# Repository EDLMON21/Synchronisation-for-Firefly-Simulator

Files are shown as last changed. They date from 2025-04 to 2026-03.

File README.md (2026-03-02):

## 🔥 Project Overview – *Synchronization for Firefly Simulator*  
### 🧠 Team Number: MON-21

👥 **Team Members:**  
- Mohammad Sami  
- Shivam Panwar  
- Gogineni Venkat Sumanth  
- Juluva Yashwanth  
- Lokesh  

---

### 📌 Problem Statement & Solution

Synchronization is a fundamental phenomenon in complex systems 🌐. To study it in real-time with flexibility, we need a programmable system with tunable parameters.

🧾 **Limitations of Old Designs:**  
The classical 1993 electronic fireflies lacked programmability and flexibility.  

⚙️ **Modern Solution:**  
Thanks to advancements in microcontrollers, we now have digital control and customizable experimentation possibilities.

---

### 🔧 Prototyping Journey

**🧩 Initial Prototype:**  
We designed a basic STM32 board with just the microcontroller to gain hands-on experience with PCB design using **STM32G030K8T6**.

**🔁 Second Iteration:**  
Integrated IR LEDs, photodiodes, and supporting components onto the board. Fabricated 2-3 units to test functionality, sync accuracy & design refinements.

**✅ Final Prototype:**  
After validation, we manufactured **9 boards (3×3 matrix)** for full-scale synchronization testing.

💻 Throughout, software development and debugging ran parallel to hardware iterations for smooth integration.

🧑‍🏫 The **STM32G030X** was suggested by our professor due to its suitability.  
🔦 The IR LED & photodiode combo was chosen for ambient light resistance and reliability in synchronization.

---

### ⚙️ Component Choices

- **🔲 STM32G030K8T6**  
  → Chosen from STM32G030 series (as fixed by prof) due to sufficient specs, easy soldering & availability.

- **🔦 IR LED & Phototransistor Pair**  
  → *SFH 4550 & SFH 309 FA*  
  → IR avoids visible light interference. The photodiode has peak sensitivity near **850nm** (matching our IR LED) and a narrow FOV for accurate detection.

- **🧰 Other Components**  
  → Transistors, LDO, micro USB connectors – sourced from WEL stock.

---

### 🚀 Running the Application

1. **🎯 Microcontroller:**  
   - STM32G030K8T6 or STM32G030K6T6  

2. **🛠 IDE:**  
   - STM32CubeIDE  

3. **📥 Compilation & Upload Steps:**  
   - Install **STM32CubeIDE**  
   - Download the `final.ioc` file from the **STM32G030K8T6** folder inside `src`  
   - Load `.ioc` file in your IDE  
   - Save the file to auto-generate code  
   - Replace the generated `main.c` with the `main.c` from the same folder  
   - Build the project 🏗️  
   - Flash the code using **StLink V2** (or equivalent)  
   - 🎉 Synchronization begins once phototransistors start detecting LED flashes!

---

Final Product
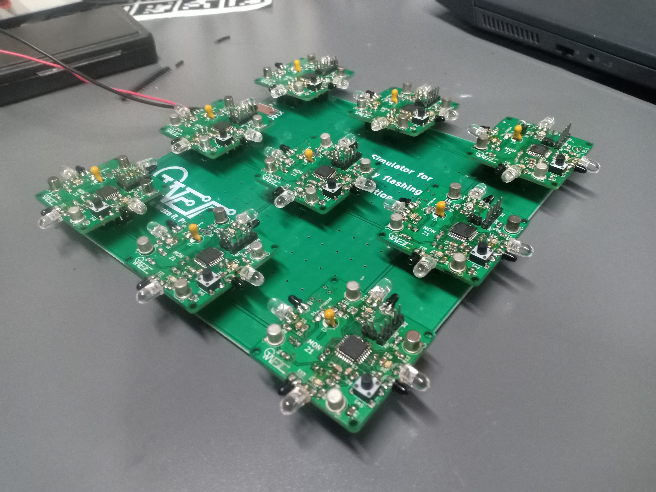
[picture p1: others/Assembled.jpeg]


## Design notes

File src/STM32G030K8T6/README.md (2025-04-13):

### Description

## Key Algorithm Components:
1. **Phase-based oscillator:** Each board maintains a phase variable (0.0 to 1.0) that continuously increases over time. When it reaches 1.0, the board flashes its LEDs and resets the phase to 0.
2. **Photodiode detection:** The algorithm continuously samples the four photodiodes and detects when a neighboring board flashes (ADC value < 500).
3. **Phase response curve:** When a flash is detected from a neighbor, the board adjusts its own phase according to:
- If early in cycle (phase < 0.5): Advance the phase slightly
- If late in cycle but not about to flash: Delay slightly
- If very near firing (phase > 0.9): Flash immediately
4. **Small randomization:** To break deadlocks and prevent persistent desynchronization, small random variations are added to the timing.

## Implementation Details:
- The code initializes with a random phase and period to ensure boards start off-sync
- The coupling strength parameter (0.15) controls how strongly boards influence each other
- As boards detect each other's flashes, they gradually shift their timing to match
- The algorithm handles all four edges of each PCB by monitoring all photodiodes

This approach gradually leads to complete synchronization of all 9 PCBs in the grid. The algorithm is robust against individual board variations and should work regardless of the initial configuration.

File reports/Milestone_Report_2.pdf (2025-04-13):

# EDL MON-21

## Sami - 22B3912 Sumanth - 22B3915 Shivam - 22B3965 Yashwanth - 22B1271 Lokesh - 22B3906

# Feedback from milestone-1 & Action taken

### 1. Reviewer’s Feedback:

- During Milestone 1, our Team Reviewer pointed out that the algorithm used for synchronisation was not mentioned in our documentation.

### 2. Clarification from Team Guide :

- Upon seeking clarification, professor Mukul informed us that synchronisation details are not required at this stage.
- Instead, he provided three research papers related to controlling the flash mechanism using a microcontroller and an RC circuit-inspired approach.

### 3. Understanding the Flash Control Mechanism:

- The Microcontroller is responsible for implementing the RC circuit-like behaviour.
- The Microcontroller modulates the charging and discharging cycle , ensuring that the LED flashes at the desired intervals and turns off suddenly.
- This process mimics the characteristic exponential charging curve of an RC circuit , creating a controlled and predictable flash cycle.

### 4. Incorporation in Milestone 2:

- We have studied the given research papers and incorporated relevant insights into our updated documentation.

# Progress evaluation against test plan

## We have successfully developed Version 1 and Version 2 of both the schematic and

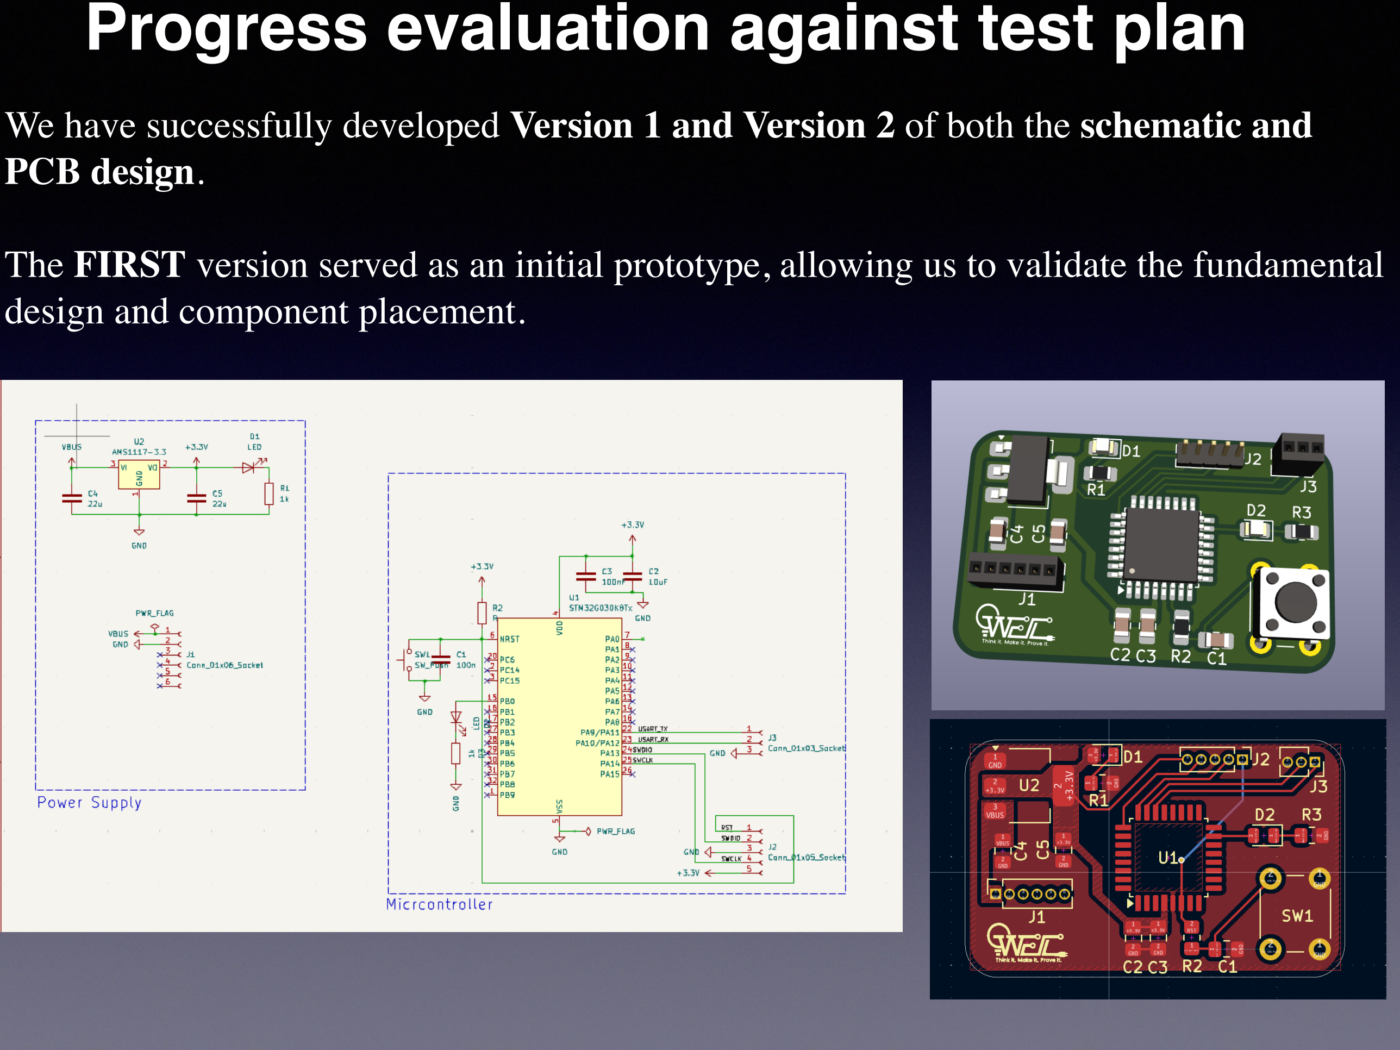
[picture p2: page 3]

PCB design.

## The FIRST version served as an initial prototype, allowing us to validate the fundamental

design and component placement.

## Based on our observations and feedback, we made necessary refinements and

improvements, leading to Version 2.

## This updated version incorporates optimisations for better performance, reliability, and

layout efficiency, bringing us closer to a finalised design.

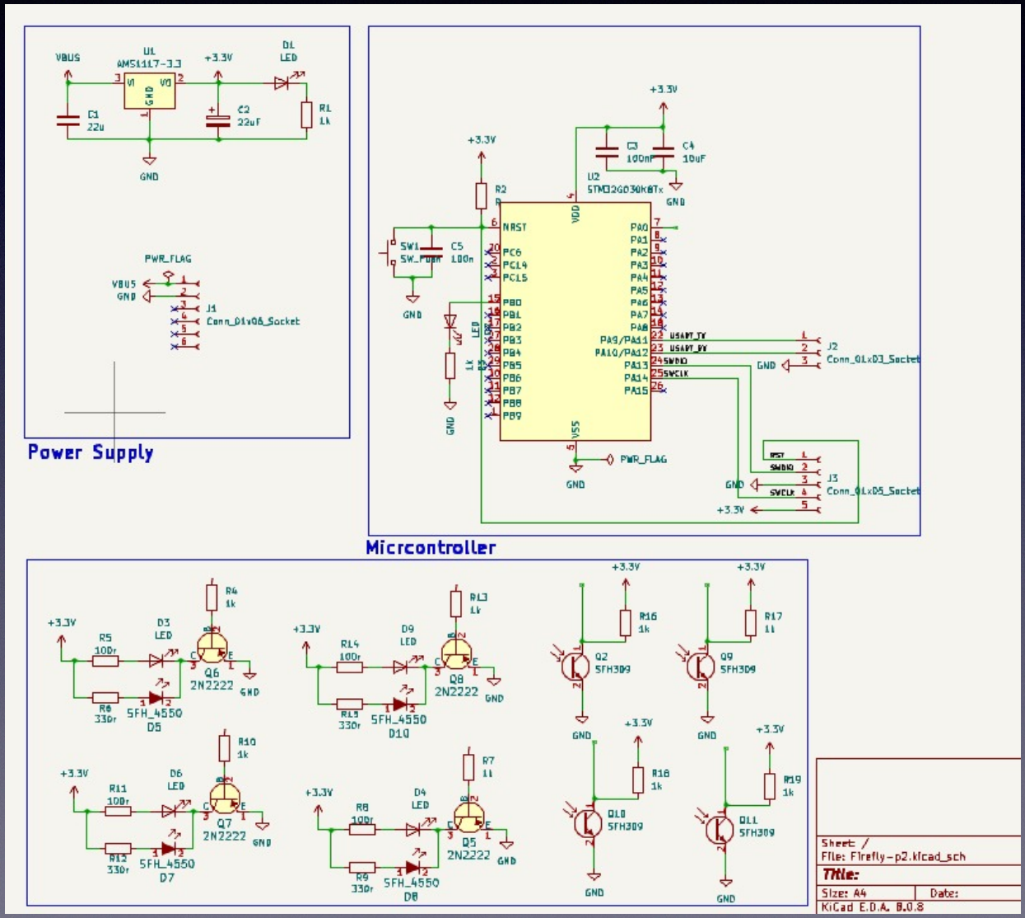
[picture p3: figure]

# Block Diagram Overview

The block diagram represents the key subsystems involved in simulating firefly synchronisation, detailing their principle of operation, signal conditioning, voltage/current levels, and

communication protocols. | Microcontroller Unit (STM32G030x)

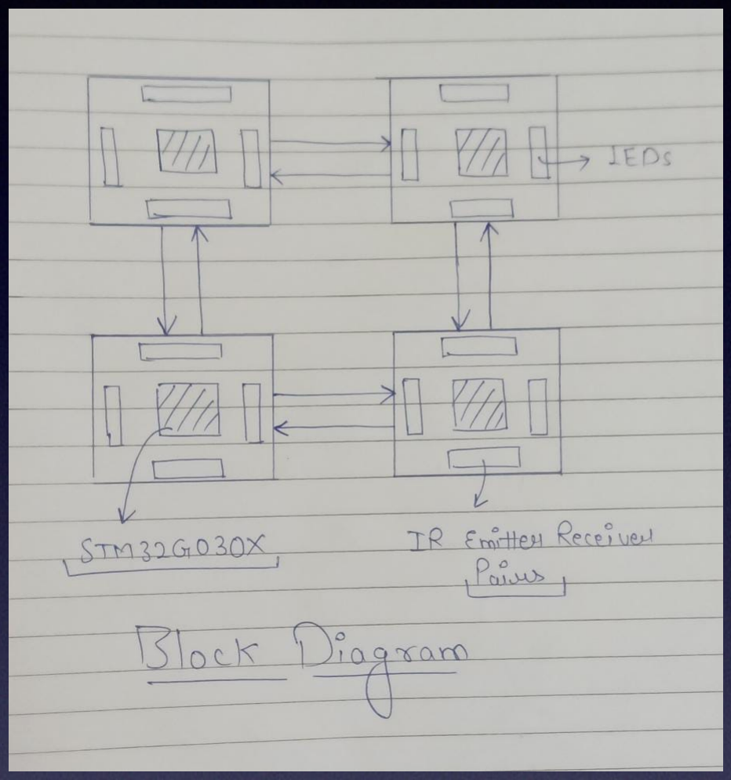
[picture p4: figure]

| • Principle of Operation:
| ◦ Serves as the core controller for the firefly synchronisation simulation. ◦ Implements the RC circuit-inspired timing mechanism in software to regulate LED flashes. ◦ Uses internal timers to generate precise flashing intervals based on the synchronisation algorithm.
| • Signal Conditioning:
| ◦ Utilises timers (TIMx) to control LED blinking with precise timing. ◦ Configures GPIOs for LED driving and communication with other units if needed. ◦ Implements interrupt-based synchronisation to handle incoming pulses from neighbouring fireflies.
| • Key Voltage & Current Levels:
| ◦ Operates at 3.3V, with GPIO logic levels matching the same voltage. ◦ LED driving through GPIOs with current-limiting resistors to maintain safe operation.

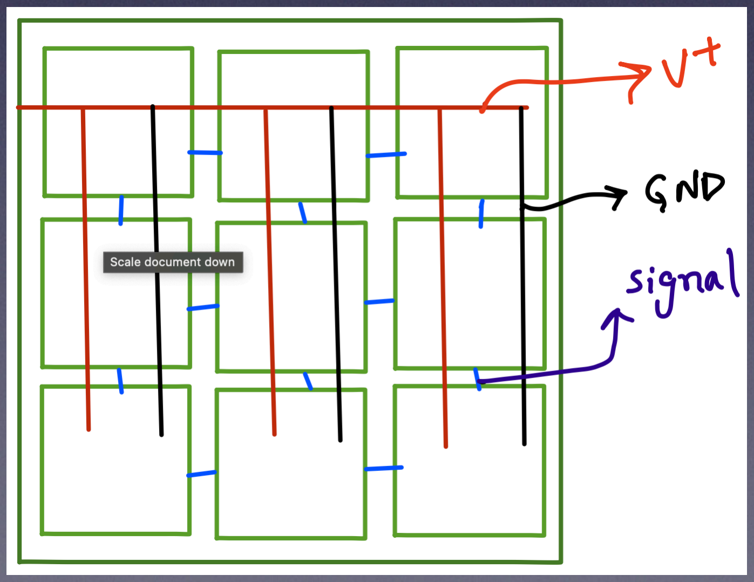
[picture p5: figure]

| • Signal Protocols:
| ◦ Uses PWM (Pulse Width Modulation) via TIM peripherals to control LED brightness and flashing pattern. ◦ External interrupts (EXTI) can be utilised for detecting synchronisation pulses.

The 9 pcbs will be mount on a base board which will be connected via the V+ voltage and a common ground

### Firefly Synchronisation - Simple Explanation

### 1. Each firefly has its own timer

- Imagine every firefly has a tiny clock inside.
- This clock slowly counts up, and when it reaches a limit, the firefly flashes.

### 2. Flashing and Resetting

- When a firefly flashes, it resets its clock to zero and starts counting up again.

### 3. Fireflies Copy Each Other

- If a firefly sees another one flash nearby, it adjusts its own timing slightly to match.
- If it's close to flashing, it flashes sooner.

### 4. Chain Reaction

- As more fireflies copy each other, their flashes start lining up.
- Over time, they all flash together in sync.

### 5. End Result

- At first, the flashes are random.
- Slowly, they start getting closer.
- After a while, all fireflies flash at the exact same time—without any central control.

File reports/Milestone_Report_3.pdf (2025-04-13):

### MON-21: Mohammad Samiuddin Shafi (22B3912) Shivam Panwar (22B3965) Sumanth Gogineni (22B3915) Lokesh Borra (22B3906) Yashwanth Juluwa (22B1271)

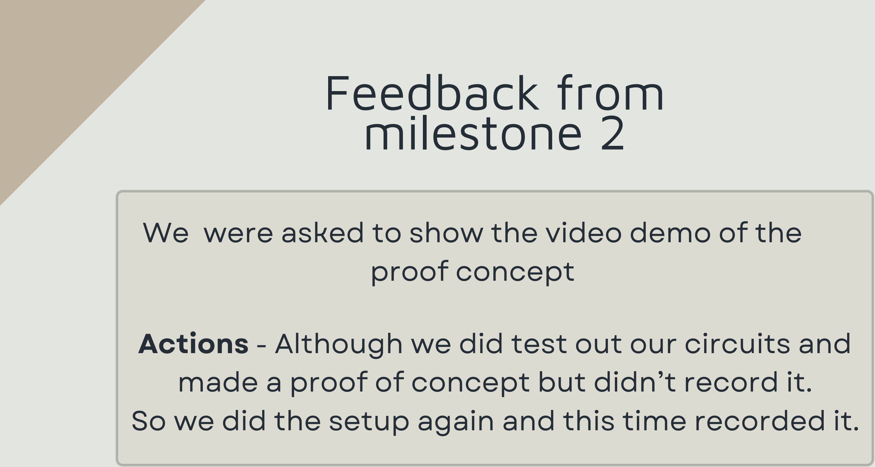
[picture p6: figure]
Feedback from milestone 2

### video link: https://drive.google.com/file/d/1-QQgroPthyP-

19S8QJT4wVglCEQSemxp/view?usp=sharing (https://drive.google.com/file/d/1-QQgroPthyP-19S8QJT4wVglCEQSemxp/view?usp=sharing)

# PCB review

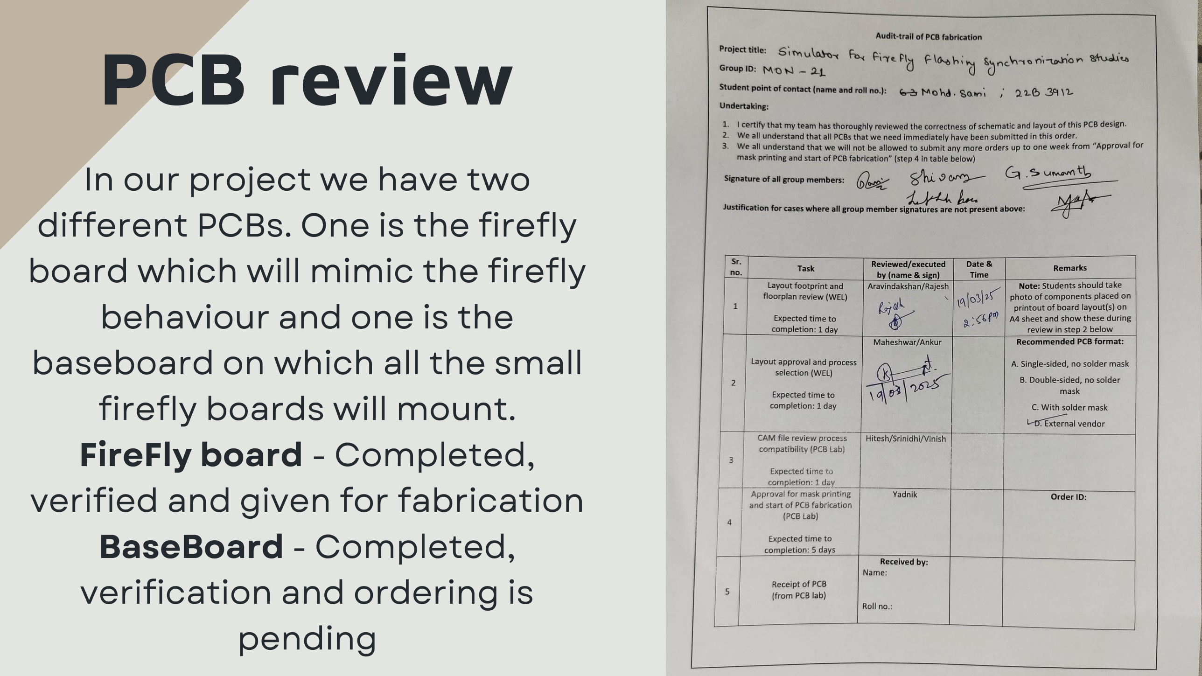
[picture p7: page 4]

# FireFly Board - Top view

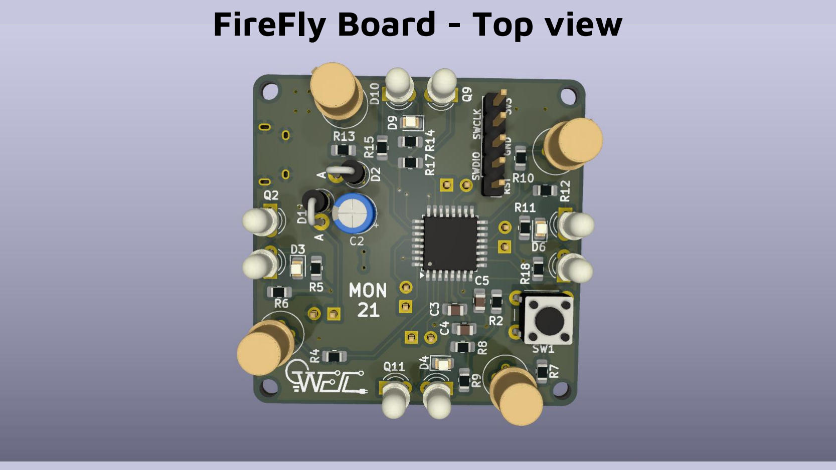
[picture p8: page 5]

# FireFly Board - Bottom view

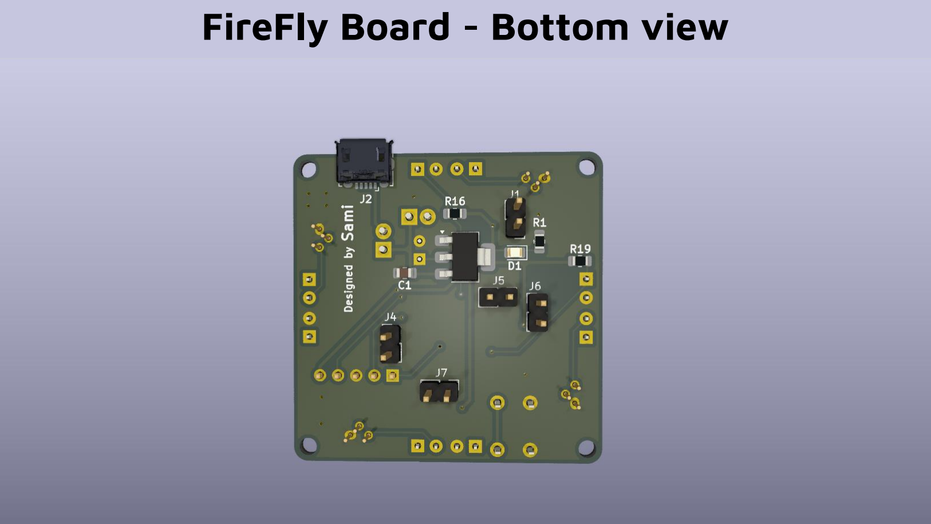
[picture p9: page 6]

# Base Board

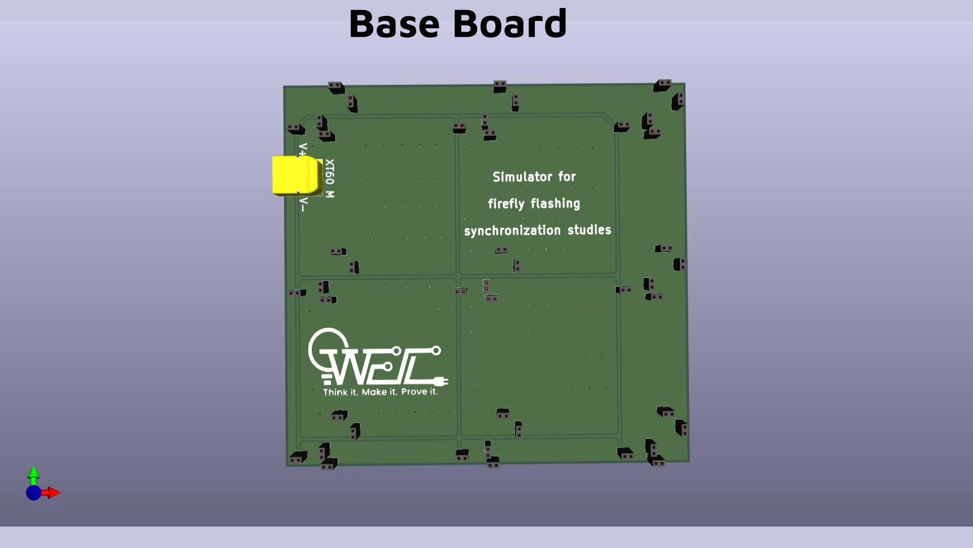
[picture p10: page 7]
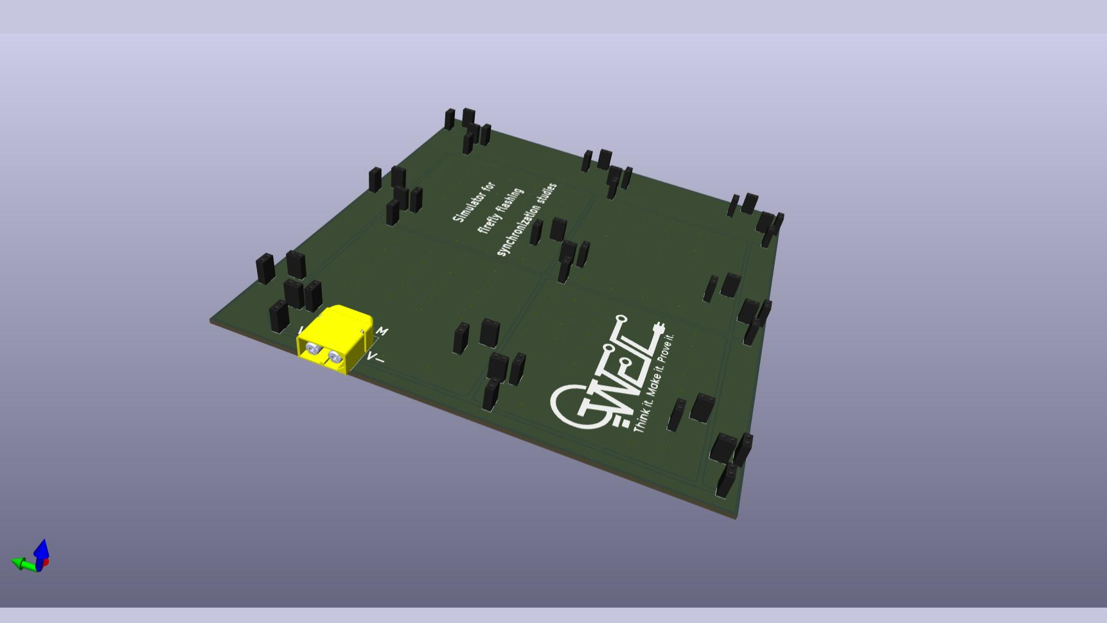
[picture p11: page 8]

# CAD Model - FireFly boards Assembled on BaseBoard

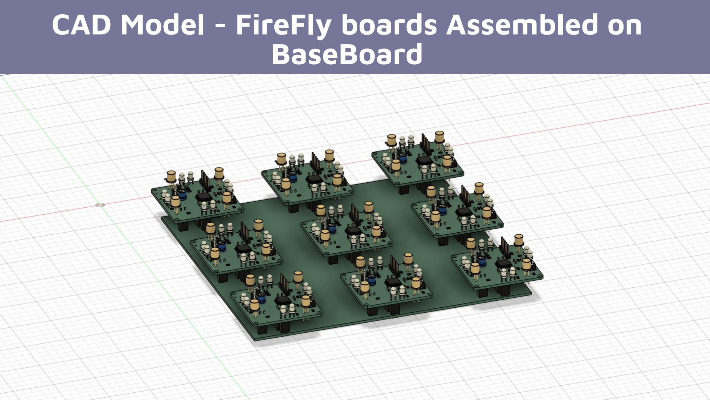
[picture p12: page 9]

# KEY LEARNINGS AND CHOICES

The choices of our components STM32G030K8T6 - STM32G030 series was fixed by the porf. then we chose this model since it was sufficient for our use case and due to ease of soldering and availability. IR LED and phototransistor pair - SFH 4550 SFH 309 FA. IR was used to avoid interference from visible and photodiode which had the max sensitivity at around 850nm (our ir led wavelength) and had a very small FOV.

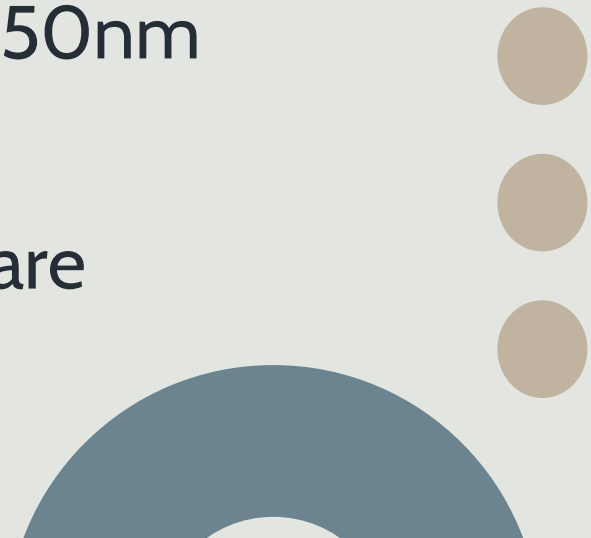
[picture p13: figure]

Other components like transistor, LDO, micro USB connector were used which are available in WEL.

We are late by 1 week. PCB should have been given for fabrication 1 week earlier.
We have less time for soldering and trouble shooting.

# PROGRESS MADE AGAINST TEST PLAN (GANTT CHART)

Original plan | Deviation

We were supposed to have
completed | the | fabrication
process. And should have started soldering the components.

# WORK DISTRIBUTION

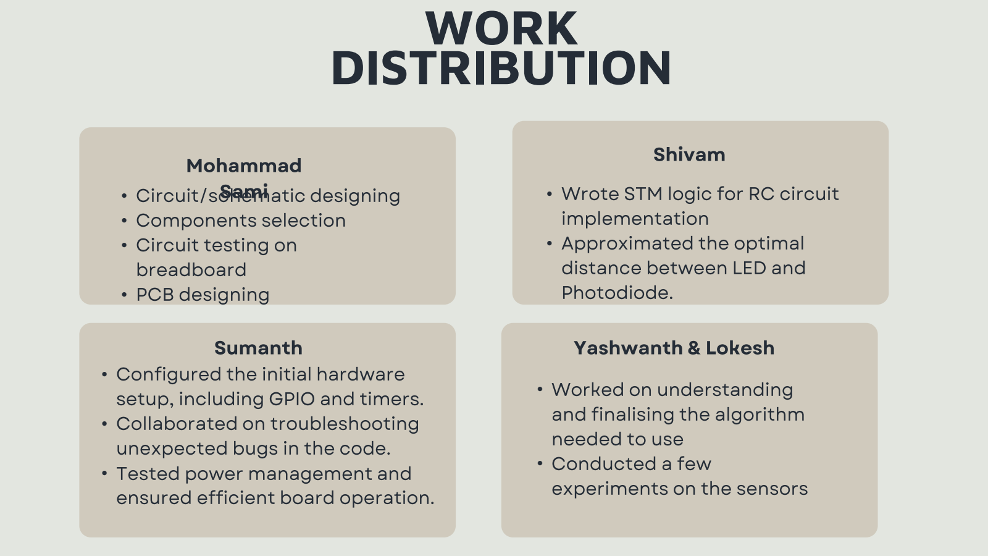
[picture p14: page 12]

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
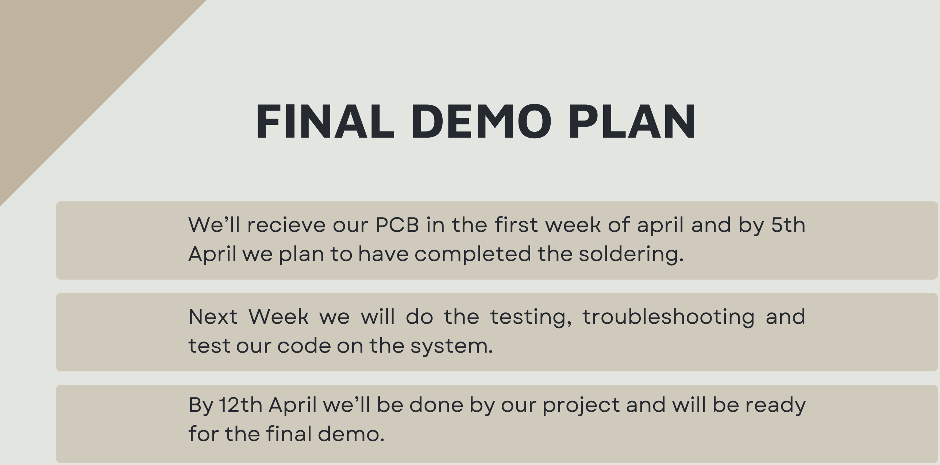
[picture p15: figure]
FINAL DEMO PLAN

# Thank You

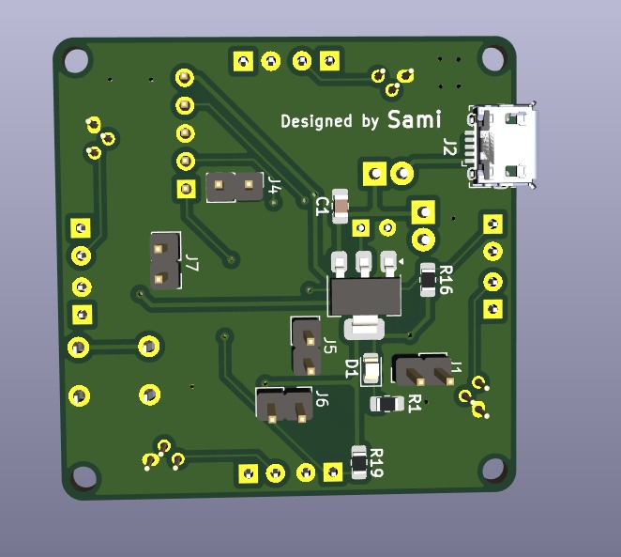
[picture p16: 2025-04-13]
pcb/firefly board/pictures/Firefly-Board-3D-Bottom.jpeg

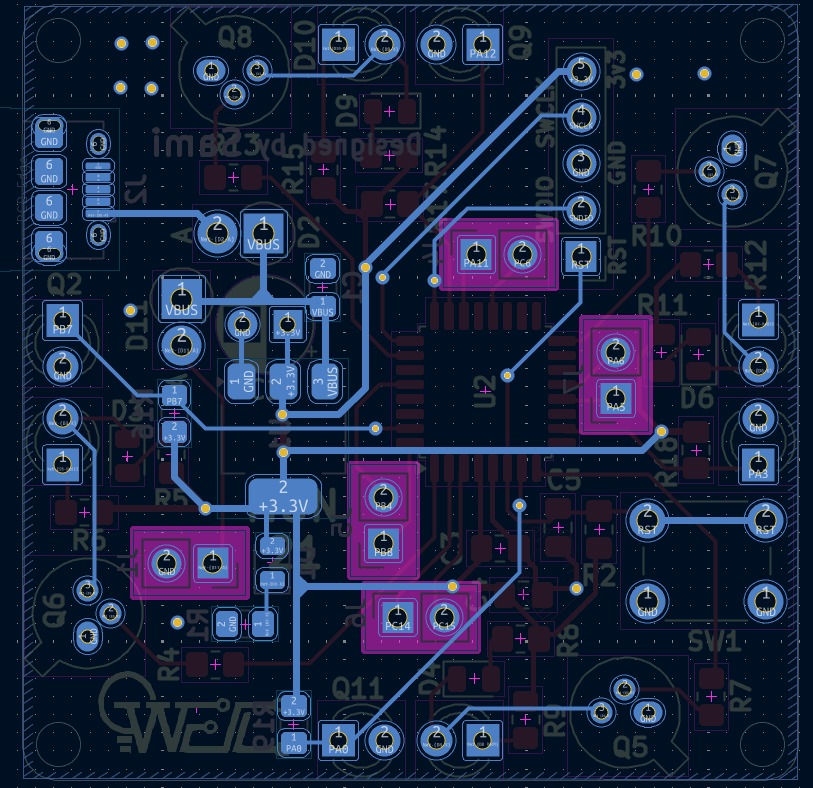
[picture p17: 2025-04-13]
pcb/firefly board/pictures/Firefly-Board-Bottomlayer.jpeg

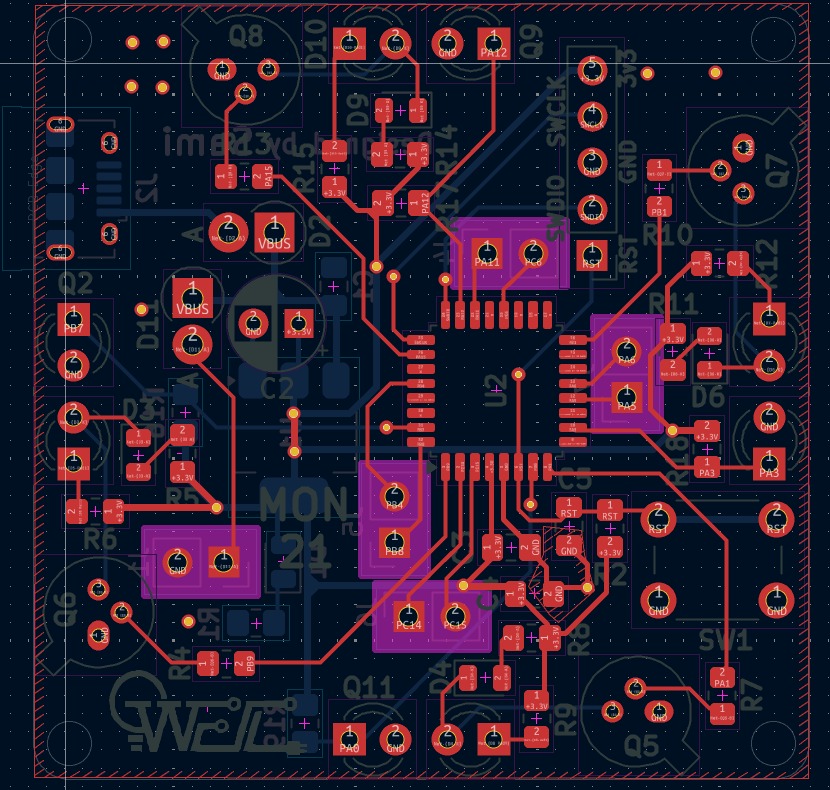
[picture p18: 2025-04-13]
pcb/firefly board/pictures/Firefly-Board-Toplayer.jpeg

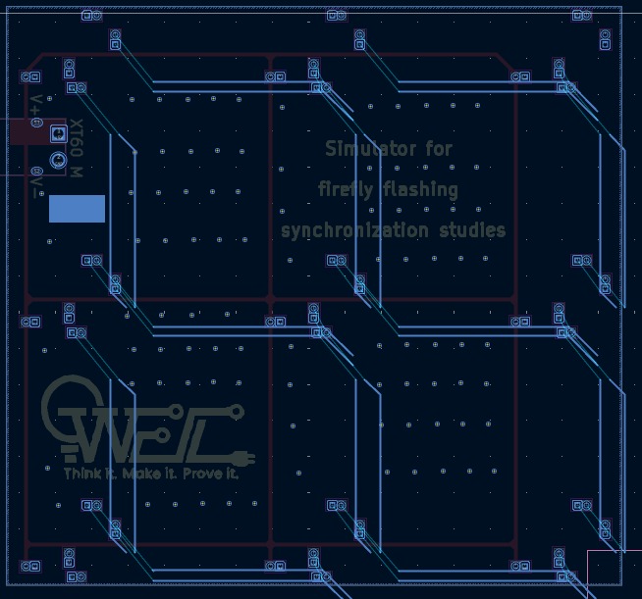
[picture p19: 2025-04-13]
pcb/base board/pictures/Baseboard-Bottomlayer.jpeg

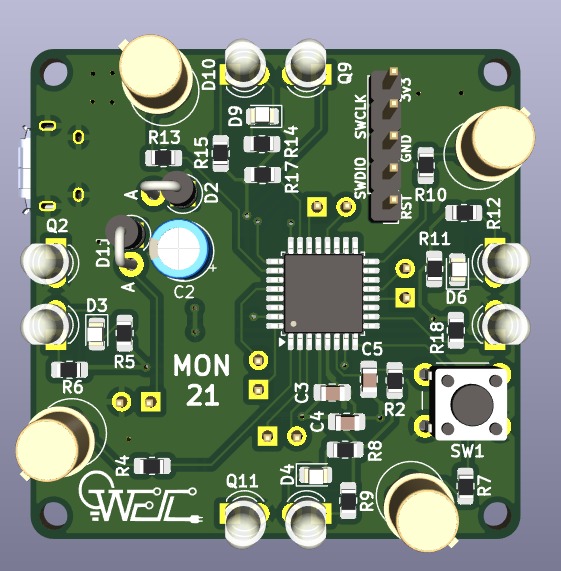
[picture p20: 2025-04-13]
pcb/firefly board/pictures/Firefly-Board-3D-Top.jpeg

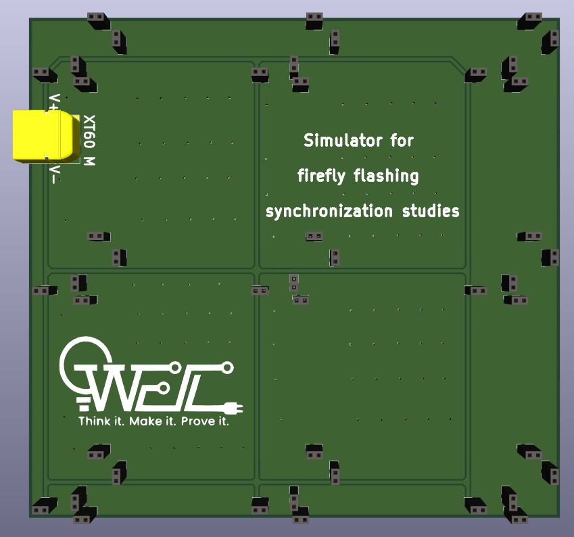
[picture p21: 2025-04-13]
pcb/base board/pictures/Baseboard-3D-Top.jpeg

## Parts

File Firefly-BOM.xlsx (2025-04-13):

Name | Qty | Value | Footprint | Type | Supplier | Cost (Rs.)
Capacitor | 1 | 22uF | Capacitor_SMD:C_0805_2012Metric_Pad1.18x1.45mm_HandSolder | Consumable | WEL | NA
Tantalum Capacitor | 1 | 22uF | Capacitor_THT:CP_Radial_D4.0mm_P1.50mm | Consumable | Robu (https://robu.in/product/22uf-16v-tantalum-capacitor-dip-pack-of-5/) | 99/-
Capacitor | 2 | 100nF | Capacitor_SMD:C_0805_2012Metric_Pad1.18x1.45mm_HandSolder | Consumable | WEL | NA
Capacitor | 1 | 10uF | Capacitor_SMD:C_0805_2012Metric_Pad1.18x1.45mm_HandSolder | Consumable | WEL | NA
LEDs | 5 | LED | LED_SMD:LED_0805_2012Metric | Consumable | WEL | NA
Schottky Diode | 2 | D_Schottky | Diode_THT:D_DO-41_SOD81_P2.54mm_Vertical_AnodeUp | Consumable | Robu (https://robu.in/product/1n5817-multicomp-pro-1n5817-schottky-rectifier-20v-1a-do-41/) | 9/-
IR Led | 4 | SFH_4550 | LED_THT:LED_D3.0mm_Clear | Consumable | RS Deliveries (https://in.rsdelivers.com/en/product/ams-osram/sfh-4550/sfh-4550-ams-osram-860nm-ir-led-5mm-t-1-3/4-through-hole-package/6548968) | 46/-
Pin Header | 1 | Power_line | Connector_PinHeader_2.54mm:PinHeader_1x02_P2.54mm_Vertical | Consumable | WEL | NA
Micro USB Receptor | 1 | USB_B_Micro | Connector_USB:USB_Micro-B_Amphenol_10118194-0001LF_Horizontal | Consumable | WEL | NA
Pin Header | 1 | Conn_01x05_Socket | Connector_PinHeader_2.54mm:PinHeader_1x05_P2.54mm_Vertical | Consumable | WEL | NA
Pin Header | 1 | line_2 | Connector_PinHeader_2.54mm:PinHeader_1x02_P2.54mm_Vertical | Consumable | WEL | NA
Pin Header | 1 | line_3 | Connector_PinHeader_2.54mm:PinHeader_1x02_P2.54mm_Vertical | Consumable | WEL | NA
Pin Header | 1 | line_4 | Connector_PinHeader_2.54mm:PinHeader_1x02_P2.54mm_Vertical | Consumable | WEL | NA
Pin Header | 1 | line_1 | Connector_PinHeader_2.54mm:PinHeader_1x02_P2.54mm_Vertical | Consumable | WEL | NA
PhotoTransistor | 4 | SFH309 | LED_THT:LED_D3.0mm_Clear | Consumable | RS Deliveries (https://in.rsdelivers.com/bh/product/ams-osram/sfh-309-fa/sfh-309-fa-ams-osram-24-ir-phototransistor-through/6655350) | 28/-
NPN BJT | 4 | 2N2222 | Package_TO_SOT_THT:TO-18-3 | Consumable | WEL | NA
Resistor | 9 | 120r | Resistor_SMD:R_0805_2012Metric_Pad1.20x1.40mm_HandSolder | Consumable | WEL | NA
Resistor | 1 | 10k | Resistor_SMD:R_0805_2012Metric_Pad1.20x1.40mm_HandSolder | Consumable | WEL | NA
Resistor | 4 | 330r | Resistor_SMD:R_0805_2012Metric_Pad1.20x1.40mm_HandSolder | Consumable | WEL | NA
Resistor | 4 | 50k | Resistor_SMD:R_0805_2012Metric_Pad1.20x1.40mm_HandSolder | Consumable | WEL | NA
Push Button | 1 | SW_Push | Button_Switch_THT:SW_PUSH_6mm | Consumable | WEL | NA
LDO | 1 | AMS1117-3.3 | Package_TO_SOT_SMD:SOT-223-3_TabPin2 | Consumable | WEL | NA
MCU | 1 | STM32G030K8Tx | Package_QFP:LQFP-32_7x7mm_P0.8mm | IC | Robu (https://robu.in/product/stm32g030k8t6-stmicroelectronics-stm32g030k8t6-arm-mcu-stm32-family-stm32g0-series-microcontrollers-arm-cortex-m0-32-bit-64-mhz-64-kb/) | 129/-

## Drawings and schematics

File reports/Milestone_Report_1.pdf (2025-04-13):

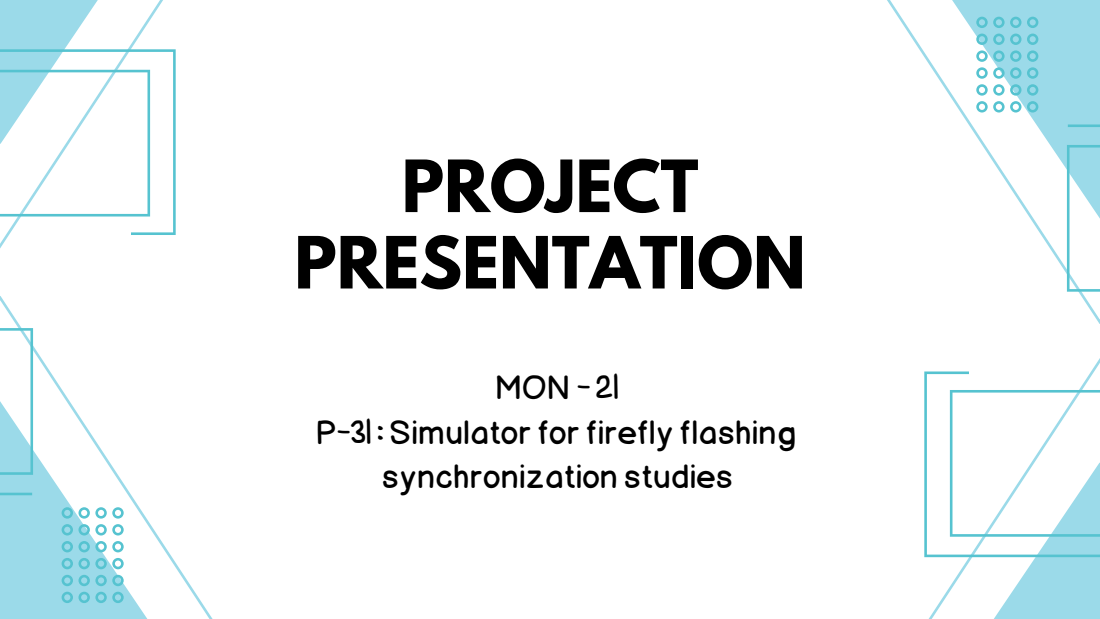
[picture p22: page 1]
MON - 21; PROJECT PRESENTATION

P-31 : Simulator for firefly flashing
synchronization studies

Nature presents us with fascinating examples of spontaneous

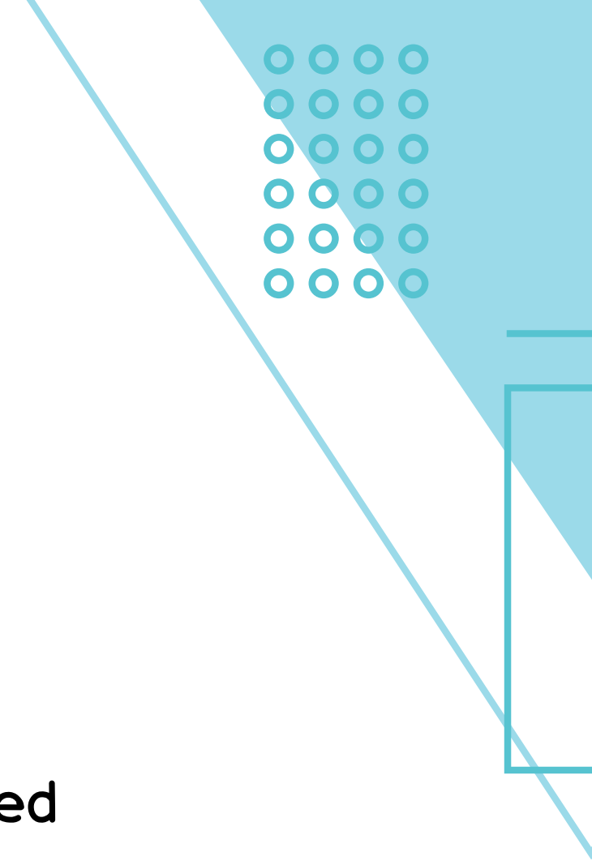
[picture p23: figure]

synchronization like the rhythmic flashing of fireflies and the synchronized

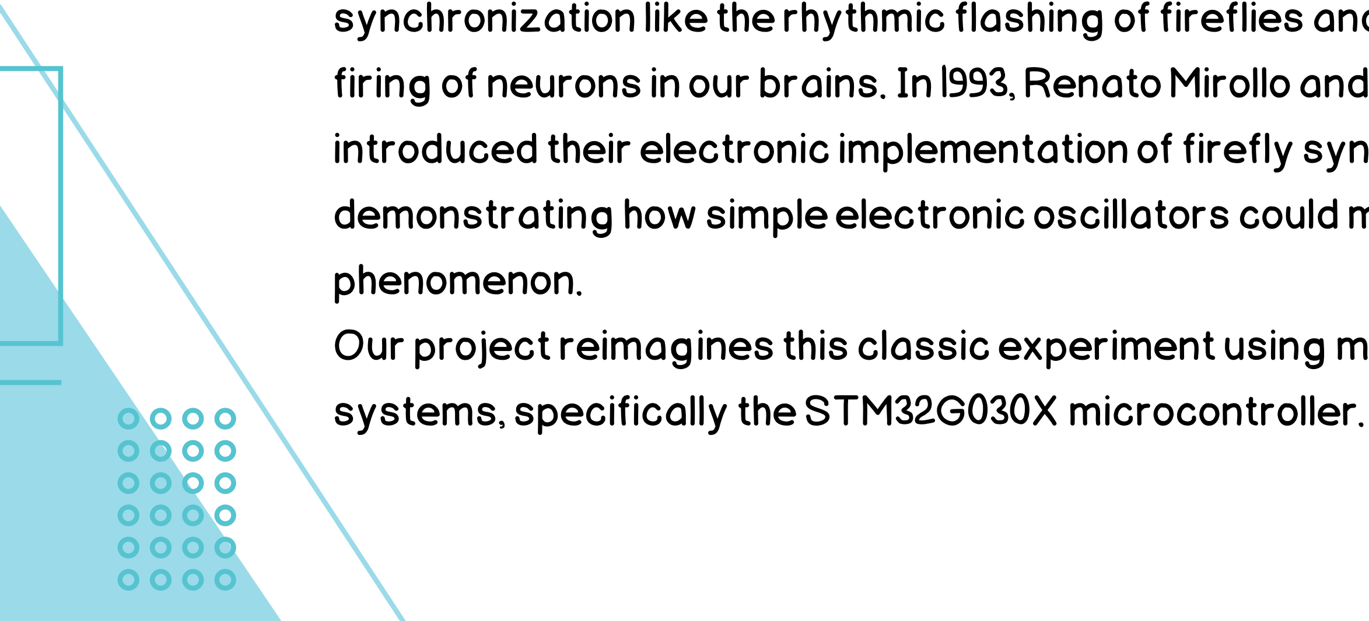
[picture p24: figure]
phenomenon.; systems, specifically the STM32G030X microcontroller.

firing of neurons in our brains. In 1993, Renato Mirollo and Steven Strogatz introduced their electronic implementation of firefly synchronization, demonstrating how simple electronic oscillators could mimic this natural

Our project reimagines this classic experiment using modern embedded

## INTRODUCTION

## PROBLEM STATEMENT

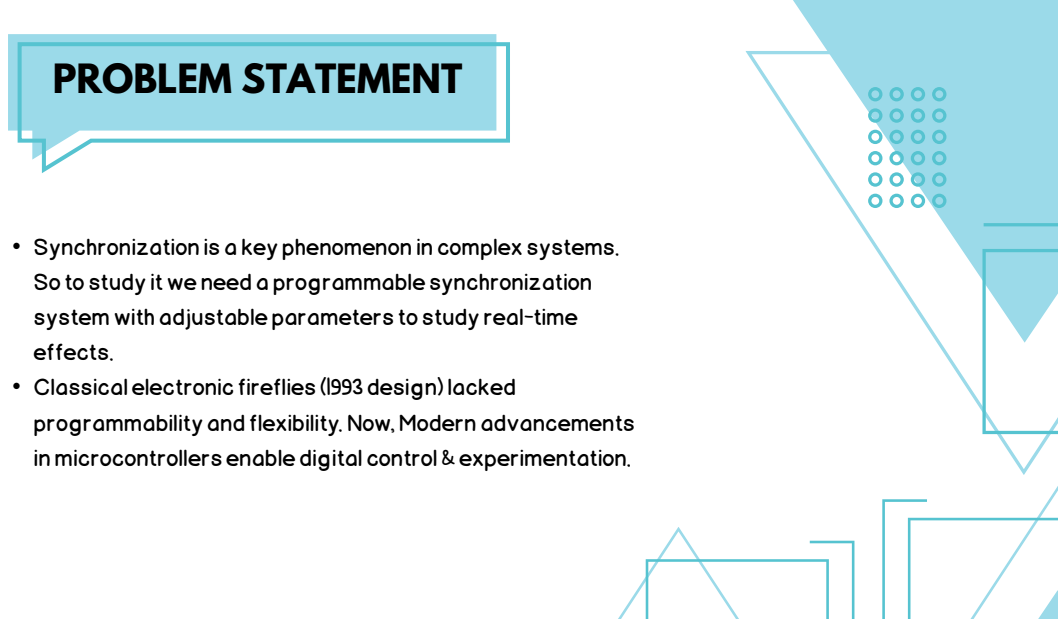
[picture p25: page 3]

• Synchronization is a key phenomenon in complex systems.
So to study it we need a programmable synchronization
system with adjustable parameters to study real-time
effects.
• Classical electronic fireflies (1993 design) lacked
programmability and flexibility. Now, Modern advancements
in microcontrollers enable digital control & experimentation.

## PROPOSED SOLUTION

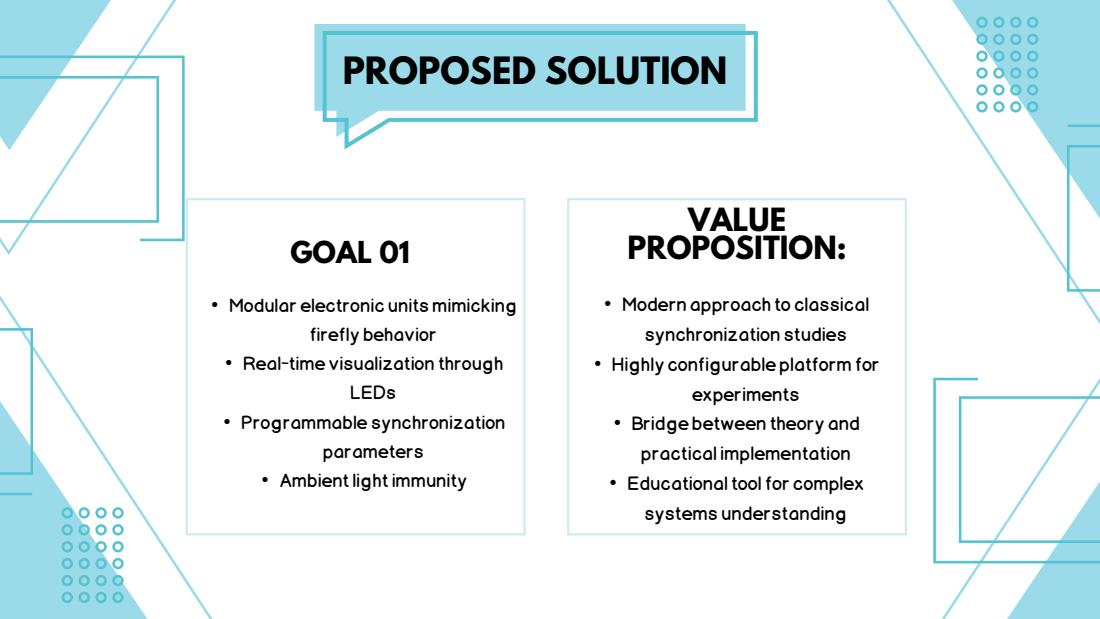
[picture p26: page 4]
GOAL 01; VALUE PROPOSITION:; firefly behavior; LEDs • Programmable synchronization; experiments

• Modern approach to classical
synchronization studies
• Highly configurable platform for

• Modular electronic units mimicking

• Real-time visualization through

• Bridge between theory and
practical implementation
• Educational tool for complex
systems understanding

parameters
• Ambient light immunity

After discussions with our professor, we have planned a three-step hardware development process:

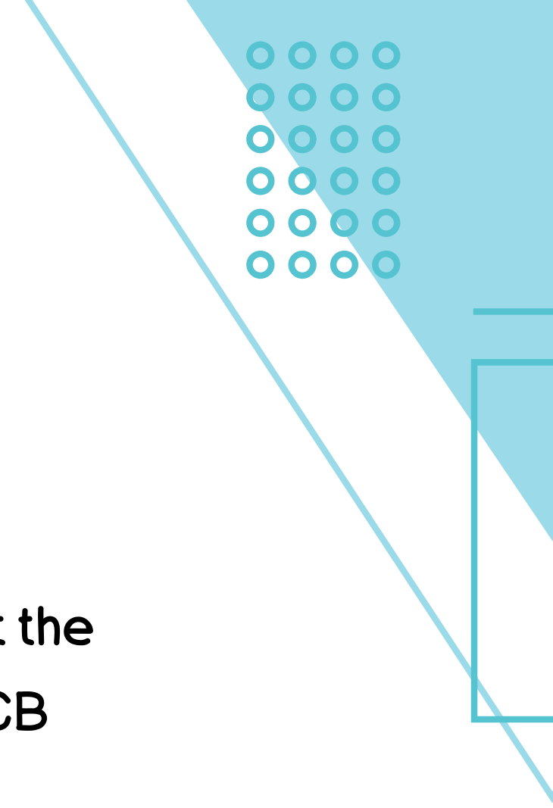
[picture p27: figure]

- Initial Prototype: We will first design a basic STM32 board with just the microcontroller. This will help us gain hands-on experience with PCB design using the STM32G030X.

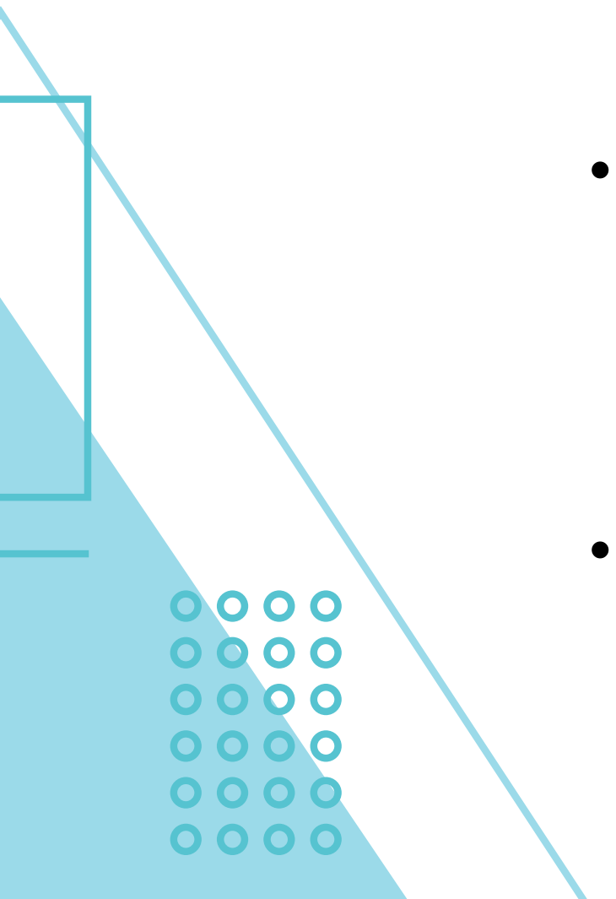
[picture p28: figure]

- Second Iteration: We will integrate IR LEDs, photodiodes, and other components onto the board and fabricate 2-3 units. These will be tested for functionality, synchronization accuracy, and any necessary design refinements.
- Final Prototype: After validating the second iteration, we will manufacture 9 boards (to form a 3×3 matrix) for full-scale testing. Any design improvements identified in the previous step will be incorporated into this version.

## METHODOLOGY & APPROACH

## METHODOLOGY & APPROACH

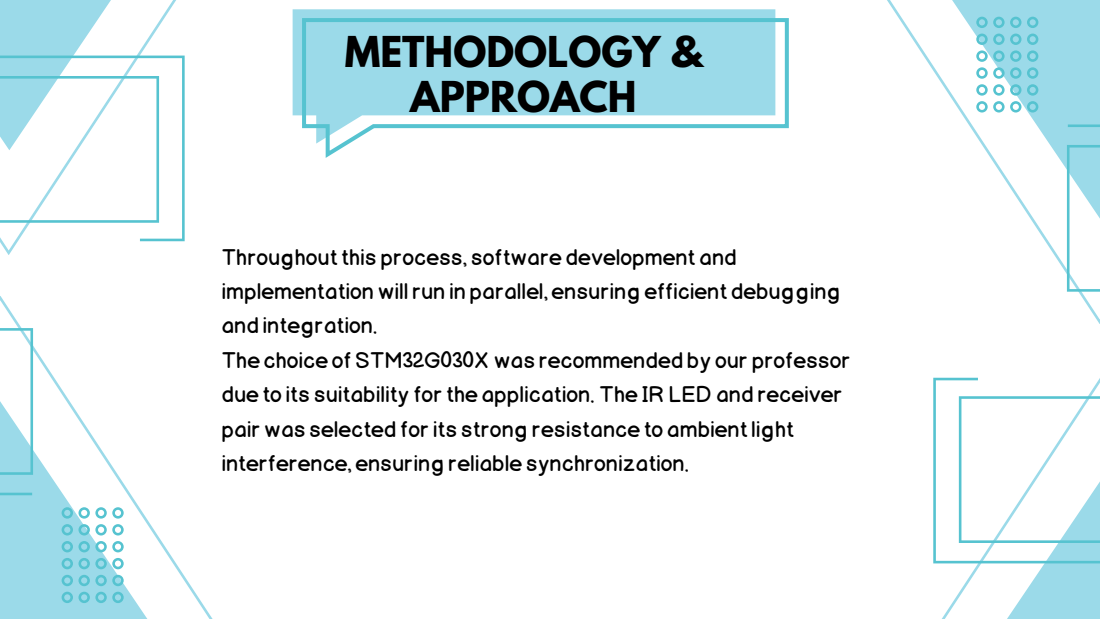
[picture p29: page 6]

Throughout this process, software development and
implementation will run in parallel, ensuring efficient debugging
and integration.
The choice of STM32G030X was recommended by our professor
due to its suitability for the application. The IR LED and receiver
pair was selected for its strong resistance to ambient light
interference, ensuring reliable synchronization.

## PRINCIPLE OF OPERATION

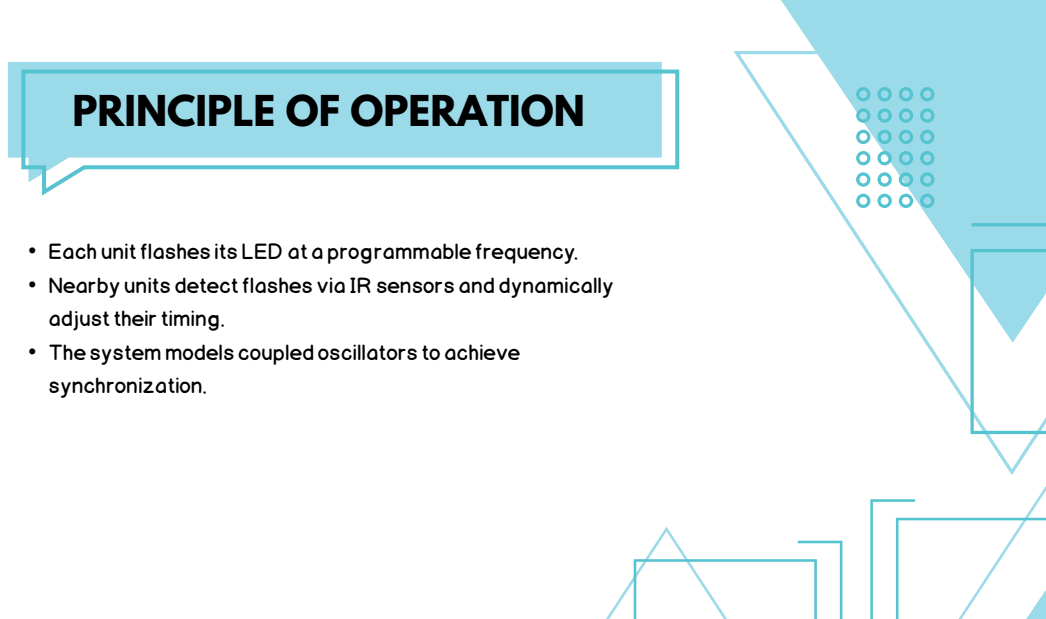
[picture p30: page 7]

• Each unit flashes its LED at a programmable frequency.
• Nearby units detect flashes via IR sensors and dynamically
adjust their timing.
• The system models coupled oscillators to achieve
synchronization.

## BLOCK DIAGRAM

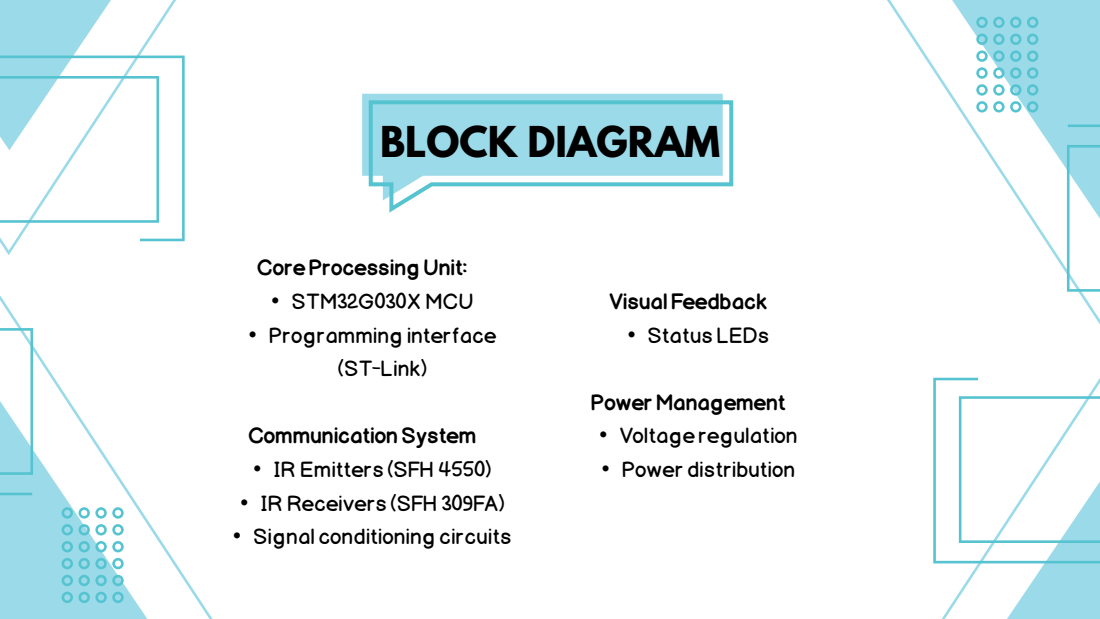
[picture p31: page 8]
(ST-Link); Visual Feedback • Status LEDs; Power Management • Voltage regulation • Power distribution

Core Processing Unit:
• STM32G030X MCU
• Programming interface

Communication System
• IR Emitters (SFH 4550)
• IR Receivers (SFH 309FA)
• Signal conditioning circuits

BLOCK DIAG.

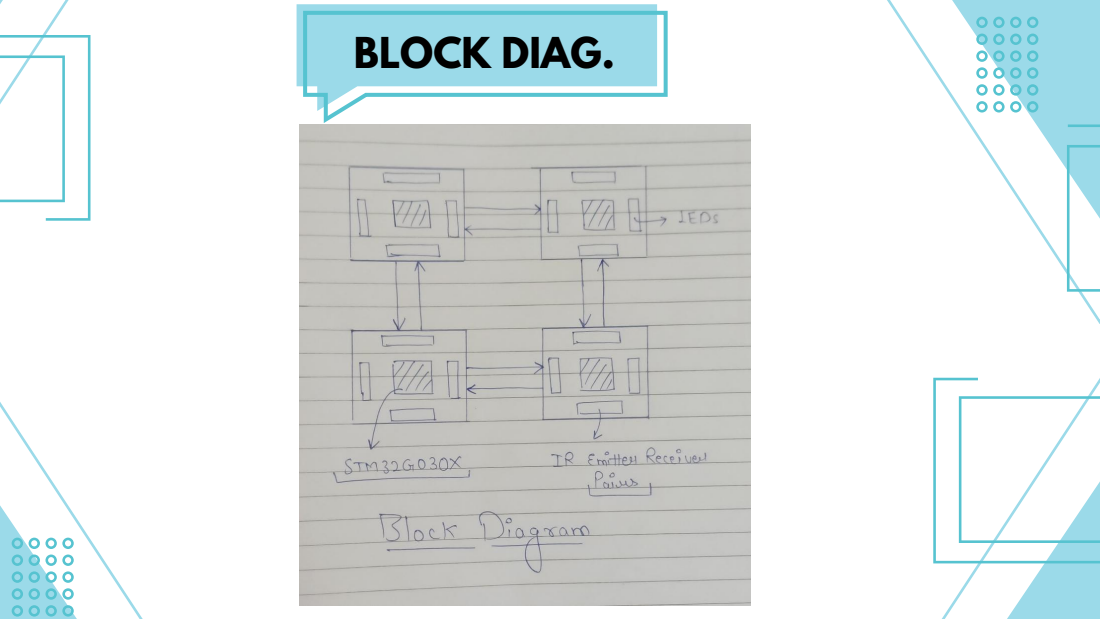
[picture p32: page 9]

## COMPONENT SELECTION JUSTIFICATION

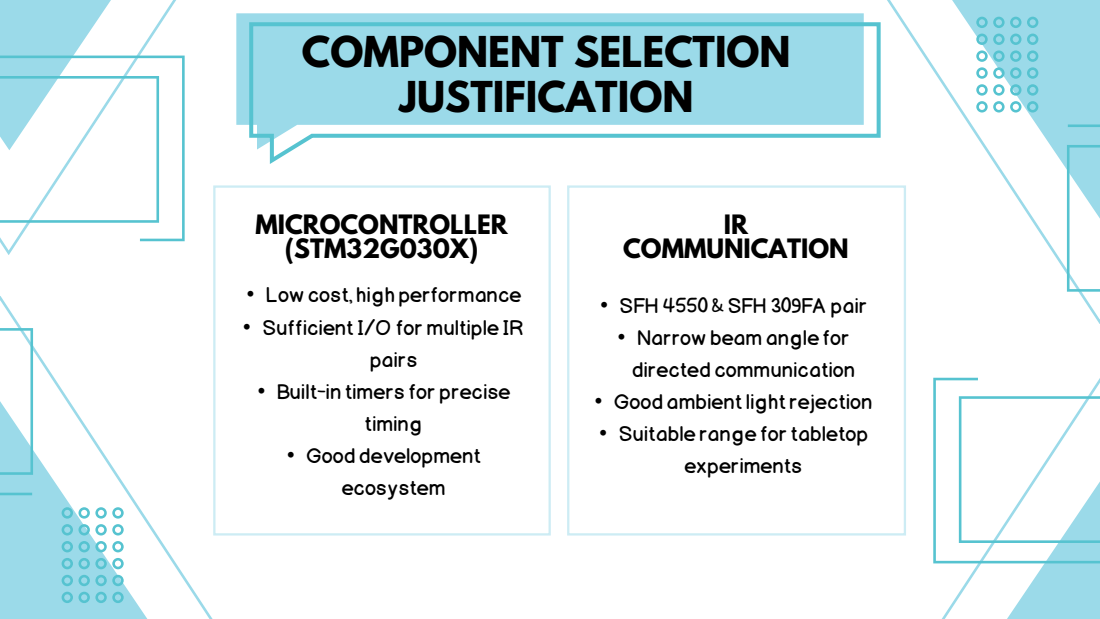
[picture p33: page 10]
MICROCONTROLLER (STM32G030X); IR COMMUNICATION; pairs; timing • Good development ecosystem; experiments

• Low cost, high performance
• Sufficient I/O for multiple IR

• SFH 4550 & SFH 309FA pair
• Narrow beam angle for
directed communication
• Good ambient light rejection
• Suitable range for tabletop

• Built-in timers for precise

## GANTT CHART


Area | Responsibilites | Member Name
1. Embedded Systems & Firmware Development
- Programming the STM32G030X microcontroller -Implementing firefly synchronization algorithms -Configuring PWM for LED intensity control -Implementing IR-based communication protocols

Shivam

2. IR Communication & Signal Processing

-Selecting appropriate IR emitters & receivers -Implementing ambient light rejection techniques -Testing and optimizing IR-based synchronization -Debugging signal inconsistencies and interference

Sumanth
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

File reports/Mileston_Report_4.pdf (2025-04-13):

MON -21; Team Members:

Mohammad Samiuddin Shafi (22B3912)
Shivam Panwar (22B3965)
Sumanth Gogineni (22B3915)
Lokesh Borra (22B3906)
Yashwanth Juluwa (22B1271)

P-31 : Simulator for firefly flashing synchronization studies; What is your project?; Who will use your product?; dynamics.

### A programmable firefly system using STM32 microcontrollers and IR

communication to explore synchronization in complex systems.

### Designed as an educational platform for professors studying coupled systems and

### Which problem faced by your user does your product solve?

Our system uses a modern microcontroller to enable programmable control, enhanced customization, and real-time experimentation.

# Status of Project


Key specifications and requirements proposed at beginning of semester | Status at end of semester | Remarks/Justification

IR communication which is immune to ambient light | Complete | Our system works perfectly in any light condition and do not need dark room to work

Synchronisation | Complete | Our fireflies synchronisation works as can be seen in the demo video

Baseboard for mounting | Complete | We said to add this as additional feature and have completed it

Different synchronization patterns | Incomplete | We have implemented natural firefly synchronization but have not yet explored more complex synchronization algorithms.

Demo Video

Thank you very much!

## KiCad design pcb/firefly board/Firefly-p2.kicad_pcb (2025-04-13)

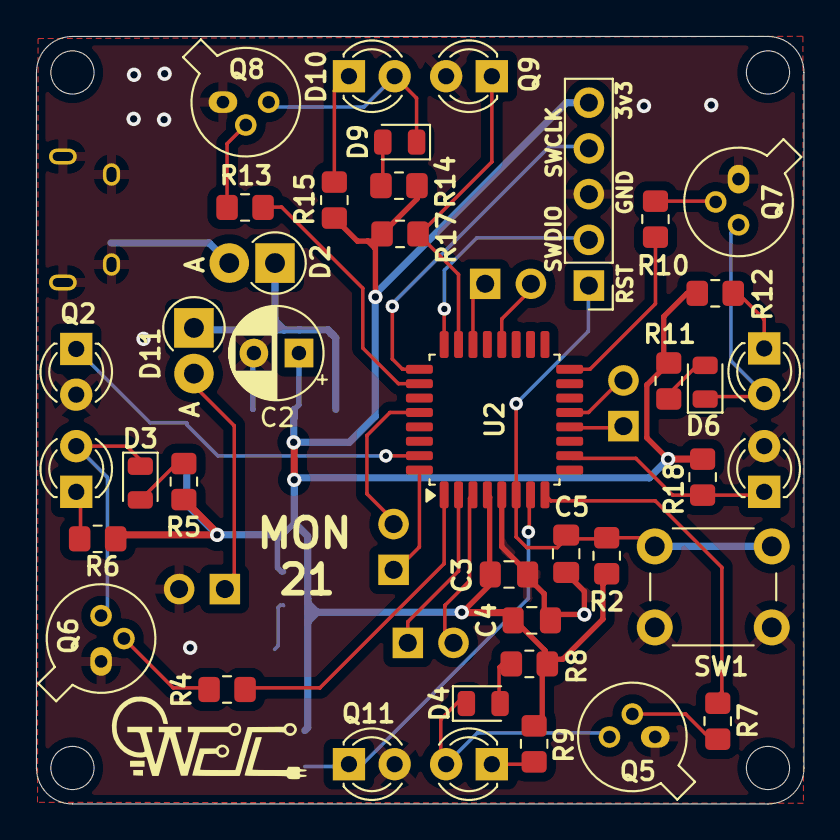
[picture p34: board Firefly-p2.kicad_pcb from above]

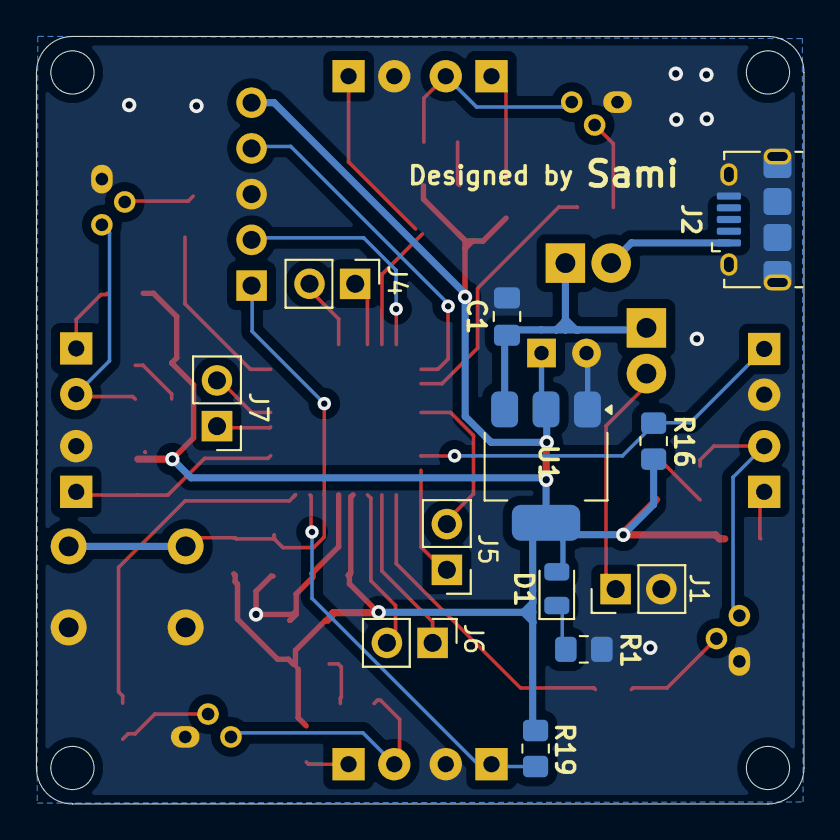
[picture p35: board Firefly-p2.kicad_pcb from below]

Board: 2 copper layers, 42.6 x 42.6 mm, 52 parts (12 on the bottom side), 41 nets.

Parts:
C1: 22u; C_0805_2012Metric_Pad1.18x1.45mm_HandSolder
C2: 22uF; CP_Radial_D5.0mm_P2.50mm
C3: 100nF; C_0805_2012Metric_Pad1.18x1.45mm_HandSolder
C4: 10uF; C_0805_2012Metric_Pad1.18x1.45mm_HandSolder
C5: 100n; C_0805_2012Metric_Pad1.18x1.45mm_HandSolder
D1, D3, D4, D6, D9: LED; LED_0805_2012Metric
D2, D11: D_Schottky; D_DO-41_SOD81_P2.54mm_Vertical_AnodeUp
D5, D7, D8, D10: SFH_4550; LED_D3.0mm_Clear
J1: Power_line; PinHeader_1x02_P2.54mm_Vertical
J2: USB_B_Micro; USB_Micro-B_Amphenol_10118194-0001LF_Horizontal
J3: Conn_01x05_Socket; PinHeader_1x05_P2.54mm_Vertical
J4: line_2; PinHeader_1x02_P2.54mm_Vertical
J5: line_3; PinHeader_1x02_P2.54mm_Vertical
J6: line_4; PinHeader_1x02_P2.54mm_Vertical
J7: line_1; PinHeader_1x02_P2.54mm_Vertical
Q2, Q9, Q10, Q11: SFH309; LED_D3.0mm_Clear
Q5, Q6, Q7, Q8: 2N2222; TO-18-3
R1, R4, R7, R10, R13: 1k; R_0805_2012Metric_Pad1.20x1.40mm_HandSolder
R2, R16, R17, R18, R19: 10k; R_0805_2012Metric_Pad1.20x1.40mm_HandSolder
R5, R8, R11, R14: 100r; R_0805_2012Metric_Pad1.20x1.40mm_HandSolder
R6, R9, R12, R15: 330r; R_0805_2012Metric_Pad1.20x1.40mm_HandSolder
SW1: SW_Push; SW_PUSH_6mm
U1: AMS1117-3.3; SOT-223-3_TabPin2
U2: STM32G030K8Tx; LQFP-32_7x7mm_P0.8mm

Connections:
+3.3V: C2.1, C3.1, C4.1, D1.2 (A), J3.5, R2.2, R5.1, R6.1, R8.1, R9.1, R11.1, R12.1, R14.1, R15.1, R16.2, R17.2, R18.2, R19.2, U1.2 (VO), U2.4 (VDD)
/PA0: Q11.1 (C), R19.1, U2.7 (PA0)
/PA1: R7.2, U2.8 (PA1)
/PA3: Q10.1 (C), R18.1, U2.10 (PA3)
/PA5: J7.1, U2.12 (PA5)
/PA6: J7.2, U2.13 (PA6)
/PA11: J4.1, U2.22 (PA9/PA11)
/PA12: Q9.1 (C), R17.1, U2.23 (PA10/PA12)
/PA15: R13.2, U2.26 (PA15)
/PB1: R10.2, U2.16 (PB1)
/PB4: J5.2, U2.28 (PB4)
/PB7: Q2.1 (C), R16.1, U2.31 (PB7)
/PB8: J5.1, U2.32 (PB8)
/PB9: R4.2, U2.1 (PB9)
/PC6: J4.2, U2.20 (PC6)
/PC14: J6.1, U2.2 (PC14)
/PC15: J6.2, U2.3 (PC15)
/RST: C5.1, J3.1, R2.1, SW1.2, U2.6 (NRST)
/SWCLK: J3.4, U2.25 (PA14)
/SWDIO: J3.2, U2.24 (PA13)
GND: C1.2, C2.2, C3.2, C4.2, C5.2, J1.2, J2.5 (GND), J2.6 (Shield), J3.3, Q2.2 (E), Q5.1 (E), Q6.1 (E), Q7.1 (E), Q8.1 (E), Q9.2 (E), Q10.2 (E), Q11.2 (E), R1.2, SW1.1, U1.1 (GND), U2.5 (VSS)
unnamed: D1.1 (K), R1.1
unnamed: D2.2 (A), J2.1 (VBUS)
unnamed: D3.2 (A), R5.2
unnamed: D3.1 (K), D5.2, Q6.3 (C)
unnamed: D4.2 (A), R8.2
unnamed: D4.1 (K), D8.2, Q5.3 (C)
unnamed: D5.1, R6.2
unnamed: D6.2 (A), R11.2
unnamed: D6.1 (K), D7.2, Q7.3 (C)
unnamed: D7.1, R12.2
unnamed: D8.1, R9.2
unnamed: D9.2 (A), R14.2
unnamed: D9.1 (K), D10.2, Q8.3 (C)
unnamed: D10.1, R15.2
unnamed: D11.2 (A), J1.1
unnamed: Q5.2 (B), R7.1
unnamed: Q6.2 (B), R4.1
unnamed: Q7.2 (B), R10.1
unnamed: Q8.2 (B), R13.1
VBUS: C1.1, D2.1 (K), D11.1 (K), U1.3 (VI)

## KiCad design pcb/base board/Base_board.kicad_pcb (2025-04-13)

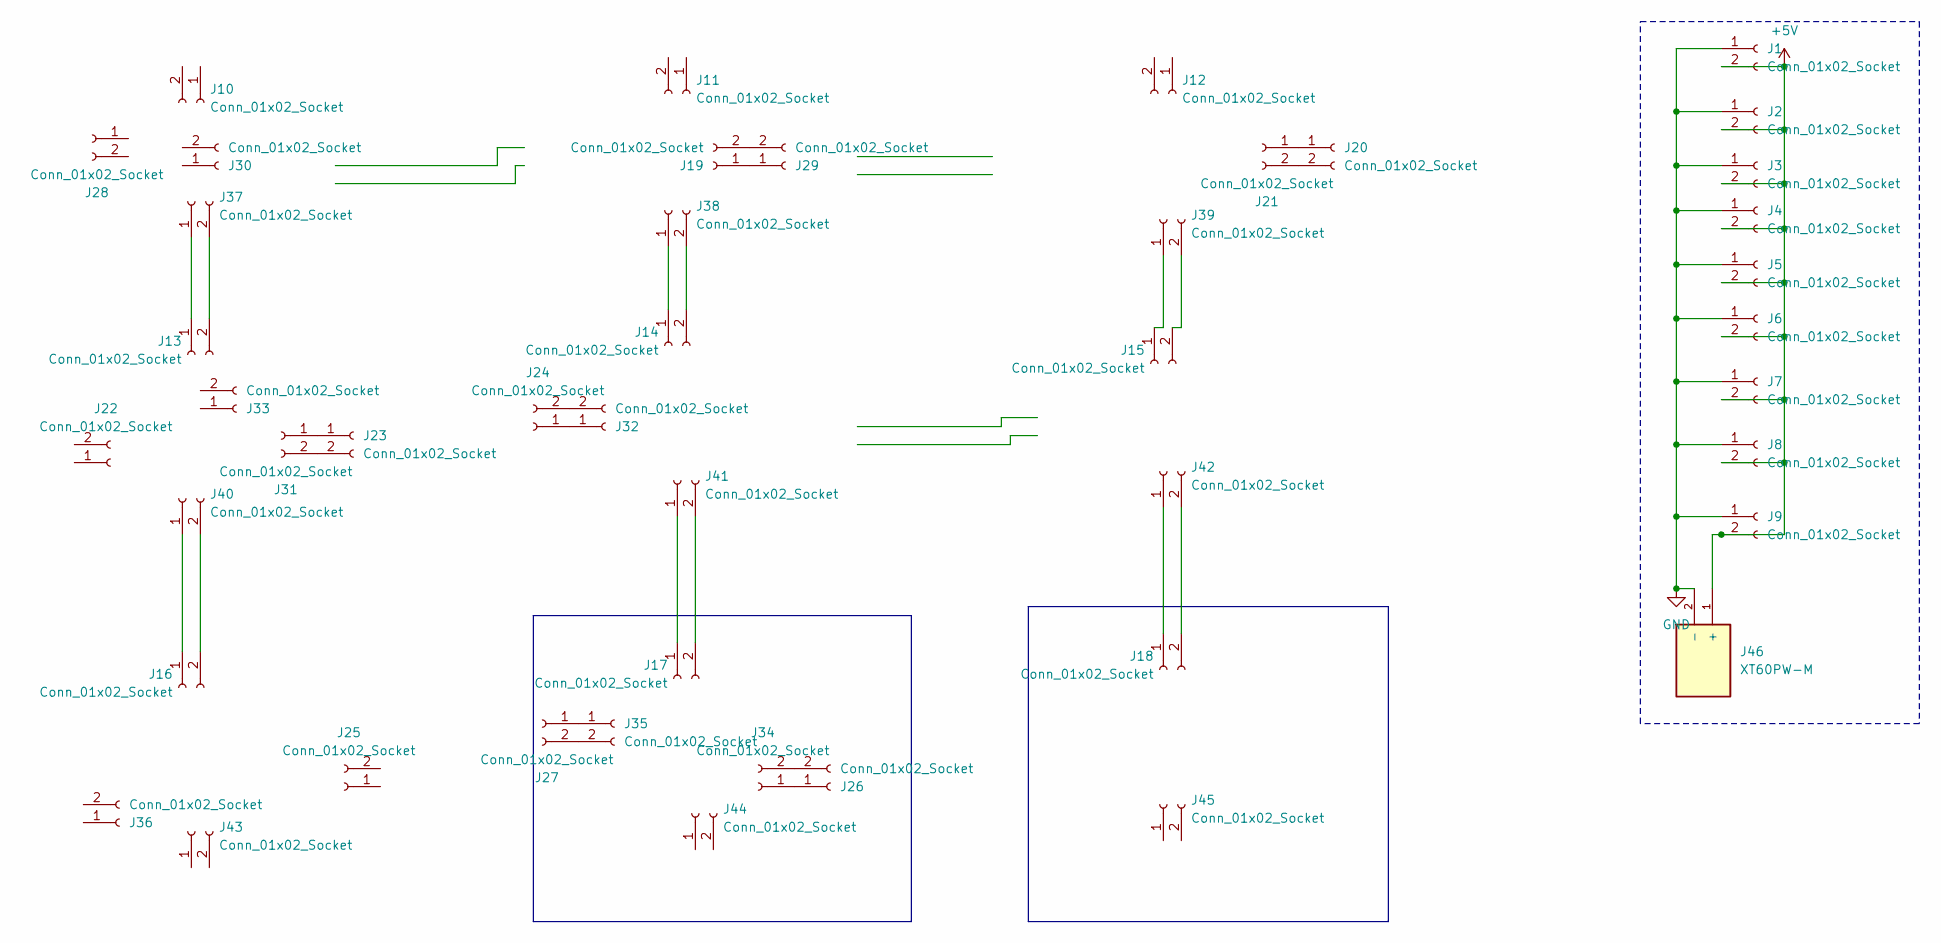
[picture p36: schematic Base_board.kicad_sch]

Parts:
J1, J2, J3, J4, J5, J6, J7, J8, J9, J10, J11, J12, J13, J14, J15, J16, J17, J18, J19, J20, J21, J22, J23, J24, J25, J26, J27, J28, J29, J30, J31, J32, J33, J34, J35, J36, J37, J38, J39, J40, J41, J42, J43, J44, J45: Conn_01x02_Socket; PinSocket_1x02_P2.54mm_Vertical
J46: XT60PW-M; AMASS_XT60PW-M; PARTREV V1.2

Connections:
+5V: J1.2, J2.2, J3.2, J4.2, J5.2, J6.2, J7.2, J8.2, J9.2, J46.1 (+)
GND: J1.1, J2.1, J3.1, J4.1, J5.1, J6.1, J7.1, J8.1, J9.1, J46.2 (-)
unnamed: J13.1, J37.1
unnamed: J13.2, J37.2
unnamed: J14.1, J38.1
unnamed: J14.2, J38.2
unnamed: J15.1, J39.1
unnamed: J15.2, J39.2
unnamed: J16.1, J40.1
unnamed: J16.2, J40.2
unnamed: J17.1, J41.1
unnamed: J17.2, J41.2
unnamed: J18.1, J42.1
unnamed: J18.2, J42.2
unnamed: J19.1, J29.1
unnamed: J19.2, J29.2
unnamed: J20.1, J21.1
unnamed: J20.2, J21.2
unnamed: J23.1, J31.1
unnamed: J23.2, J31.2
unnamed: J24.1, J32.1
unnamed: J24.2, J32.2
unnamed: J26.1, J34.1
unnamed: J26.2, J34.2
unnamed: J27.1, J35.1
unnamed: J27.2, J35.2

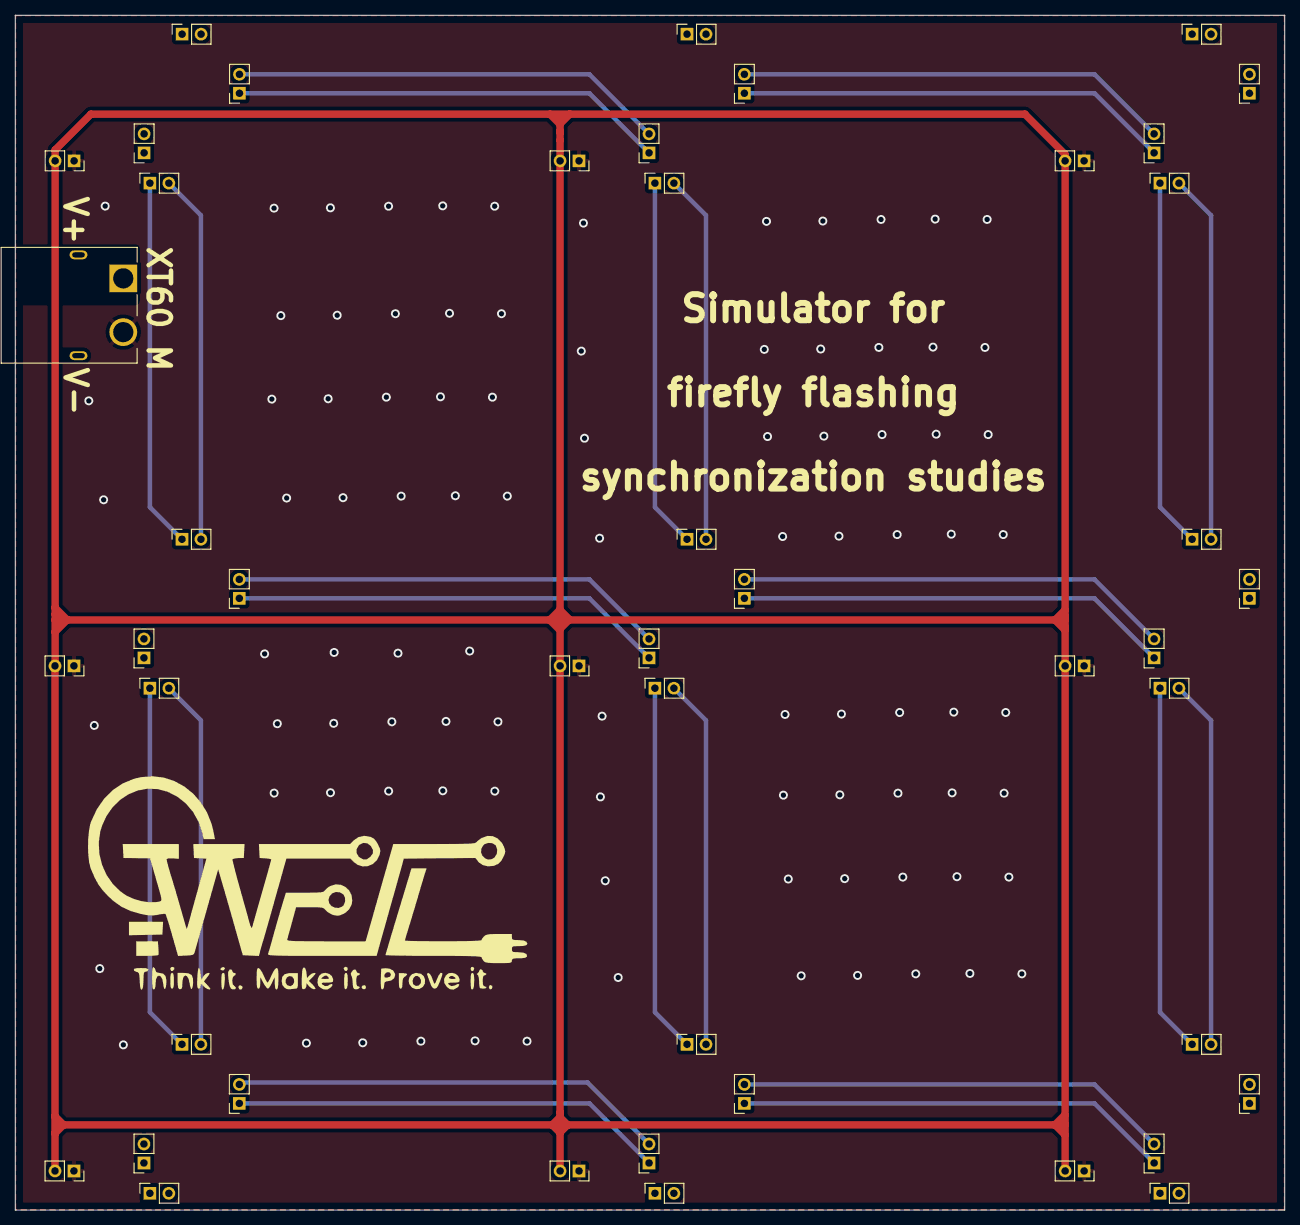
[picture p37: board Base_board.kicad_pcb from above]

Board: 2 copper layers, 170.0 x 160.0 mm, 46 parts (0 on the bottom side), 26 nets.

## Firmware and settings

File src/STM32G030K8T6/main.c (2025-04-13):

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
/* Includes ------------------------------------------------------------------*/
#include "main.h"

/* USER CODE BEGIN PD */
#define ADC_THRESHOLD 500  // Threshold for flash detection
/* USER CODE END PD */

ADC_HandleTypeDef hadc1;
DMA_HandleTypeDef hdma_adc1;

TIM_HandleTypeDef htim1;
TIM_HandleTypeDef htim3;

/* USER CODE BEGIN PV */
// Define GPIO ports and pins for LEDs
GPIO_TypeDef* led_ports[4] = {GPIOA, GPIOA, GPIOB, GPIOB};
uint16_t led_pins[4] = {GPIO_PIN_1, GPIO_PIN_15, GPIO_PIN_1, GPIO_PIN_9};

// ADC values buffer
volatile uint32_t adc_values[4] = {0};
volatile uint8_t adc_conversion_complete = 0;
/* USER CODE END PV */

void SystemClock_Config(void);
static void MX_GPIO_Init(void);
static void MX_DMA_Init(void);
static void MX_ADC1_Init(void);
static void MX_TIM1_Init(void);
static void MX_TIM3_Init(void);
/**
  * @brief  The application entry point.
  * @retval int
  */
int main(void)
{
  /* MCU Configuration--------------------------------------------------------*/

  /* Reset of all peripherals, Initializes the Flash interface and the Systick. */
  HAL_Init();

  /* Configure the system clock */
  SystemClock_Config();

  /* Initialize all configured peripherals */
  MX_GPIO_Init();
  MX_DMA_Init();
  MX_ADC1_Init();
  MX_TIM1_Init();
  MX_TIM3_Init();
  /* USER CODE BEGIN 2 */
  /* Turn off all LEDs initially */
  for (int i = 0; i < 4; i++) {
    HAL_GPIO_WritePin(led_ports[i], led_pins[i], GPIO_PIN_RESET);
  }

  /* Start timers with interrupt generation */
  HAL_TIM_Base_Start_IT(&htim1);
  HAL_TIM_Base_Start_IT(&htim3);

  /* Start ADC with DMA */
  HAL_ADC_Start_DMA(&hadc1, (uint32_t*)adc_values, 4);

  /* USER CODE END 2 */

  /* Infinite loop */
  /* USER CODE BEGIN WHILE */
  uint32_t last_toggle_time = HAL_GetTick();
  uint8_t toggle_state = 0;

  while (1)
  {
    /* USER CODE END WHILE */

    /* USER CODE BEGIN 3 */
    // Toggle all LEDs every 5 seconds to verify they work
    uint32_t current_time = HAL_GetTick();
    if (current_time - last_toggle_time >= 5000) {
      toggle_state = !toggle_state;
      for (int i = 0; i < 4; i++) {
        HAL_GPIO_WritePin(led_ports[i], led_pins[i], toggle_state ? GPIO_PIN_SET : GPIO_PIN_RESET);
      }
      last_toggle_time = current_time;
    }

    // Check ADC values when conversion is complete
    if (adc_conversion_complete) {
      adc_conversion_complete = 0;

      // Process each photodiode
      for (int i = 0; i < 4; i++) {
        // If light detected (ADC value below threshold), turn on corresponding LED
        if (adc_values[i] < ADC_THRESHOLD) {
          HAL_GPIO_WritePin(led_ports[i], led_pins[i], GPIO_PIN_SET);
        } else {
          HAL_GPIO_WritePin(led_ports[i], led_pins[i], GPIO_PIN_RESET);
        }
      }
    }

    HAL_Delay(10);
  }
  /* USER CODE END 3 */
}

/* Timer callback function */
void HAL_TIM_PeriodElapsedCallback(TIM_HandleTypeDef *htim)
{
  if (htim->Instance == TIM3) {
    // TIM3 triggers ADC conversion automatically via TRGO
  }
}

/* ADC conversion complete callback */
void HAL_ADC_ConvCpltCallback(ADC_HandleTypeDef* hadc)
{
  if (hadc->Instance == ADC1) {
    adc_conversion_complete = 1;
  }
}

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
/* USER CODE BEGIN 4 */
/* This is CRUCIAL: Make sure your interrupt handlers are defined */
void TIM1_BRK_UP_TRG_COM_IRQHandler(void)
{
  HAL_TIM_IRQHandler(&htim1);
}

void TIM3_IRQHandler(void)
{
  HAL_TIM_IRQHandler(&htim3);
}

void DMA1_Channel1_IRQHandler(void)
{
  HAL_DMA_IRQHandler(&hdma_adc1);
}

/* USER CODE END 4 */
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

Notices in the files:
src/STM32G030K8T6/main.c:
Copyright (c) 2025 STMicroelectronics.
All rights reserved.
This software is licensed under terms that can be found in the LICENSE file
